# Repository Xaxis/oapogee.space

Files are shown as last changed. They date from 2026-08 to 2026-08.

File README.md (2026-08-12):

# oApogee

An open source telemetry payload for model rockets, and the documentation that
teaches you to build one. Site at **[oapogee.space](https://oapogee.space)**.

oApogee records altitude, acceleration and orientation through a flight, logs it
to onboard flash, and optionally downlinks it live over LoRa and reports GNSS
position for recovery. It attaches to a rocket you already own, in a printed pod
that needs no modification to the airframe.

**oApogee is a passive instrumentation payload. It does not fire ejection
charges, control deployment, ignite motors, or command any pyrotechnic device.**
That is a design boundary and it will not change. See
[content/safety.md](content/safety.md).

## Project status

**This is a design on paper.** Nothing has been fabricated, assembled, weighed,
priced, or flown. Every cost, mass, range and endurance figure on the site is
missing rather than estimated, and each gap records what evidence would close
it. The full list is at [oapogee.space/status](https://oapogee.space/status),
read from the content files when the site is built so it cannot go stale.

Design decisions that are still open are in
[docs/open-questions.md](docs/open-questions.md).

## The rule everything else follows from

**Never publish a number that has not been measured or sourced.**

The documentation is the product. The hardware is commodity: barometer, IMU,
microcontroller, radio, all of it available to anyone. What makes this project
worth existing is that a motivated beginner can follow the site start to finish
and end up with a working payload and a real flight graph. That only works if
every number on it is true.

So there are no estimates dressed as measurements. A figure that has not been
verified is written as a marker saying what evidence would close it, and the
build fails if the index of those markers goes stale. A site full of confident
fabricated specs is worse than useless in a hobby where people's build decisions
depend on them.

Two consequences you will notice immediately: the bill of materials has no
prices in it, and the homepage does not have a flight graph.

## Layout

```
content/     Prose pages, Markdown with YAML frontmatter
data/        Structured source: bom.yaml, tiers.yaml, glossary.yaml
docs/        Working documents, including the page map and the format specs
apps/web/    Next.js 15 App Router site, one renderer of content/ and data/
tools/       Checks: prose rules, data cross-references, marker index
```

`content/` and `data/` are the product. `apps/web/` renders them. Anything that
appears in more than one place on the site lives in `data/` as YAML, never as a
hand-written table inside a Markdown page, because two hand-written tables drift
and nothing catches it.

## Commands

Everything is a `make` target, and CI runs the same ones. `make` lists them.

```bash
make install     # dependencies, pinned to match CI
make dev         # the site, locally
make check       # everything CI runs
make check-fast  # the same without the site build
make hw          # re-render the schematic from hardware/oapogee.tsx
```

## Contributing

The most useful contribution to this project right now is telling us where it is
wrong. The safety and regulatory pages in particular are written carefully and
have not been reviewed by anyone with formal expertise in the rules they
describe.

Read [CONTRIBUTING.md](CONTRIBUTING.md) first, then
[CONTENT-STYLE.md](CONTENT-STYLE.md). Between them they cover the accuracy rule,
the voice, and the naming conventions, all of which are enforced in CI.

## Naming

The project is **oApogee**: lowercase `o`, capital `A`, one word. The `o` stands
for open.

**It is never shortened to "Apogee."** Apogee Components is the dominant
retailer in model rocketry and owns that word in this hobby completely. There is
no short form. oApogee is not affiliated with Apogee Components.

The three tiers are oApogee Solo, oApogee Link, and oApogee Track.

## Licence

Three, because this repository holds three different kinds of thing.

| What | Licence | SPDX |
|---|---|---|
| Hardware design files | CERN Open Hardware Licence v2, Strongly Reciprocal | `CERN-OHL-S-2.0` |
| Firmware and software | Apache License 2.0 | `Apache-2.0` |
| Documentation and content | Creative Commons Attribution-ShareAlike 4.0 | `CC-BY-SA-4.0` |

Full texts in [LICENSES/](LICENSES), and [LICENSE](LICENSE) says which applies
to which files and why. Reciprocal on the board because the plausible bad
outcome is a closed volume clone; permissive on the firmware because that is the
part worth having other people embed everywhere.

**The design is open. The name is not.** Build it, sell it, fork it, call it
something else. Licences do not stop somebody shipping a clone under this name;
a trademark does.

A project named for openness that ships a black box loses the audience it was
built for, so the intent is to publish the KiCad project rather than a PDF
schematic, the parametric CAD source rather than only STLs, and the full
firmware including calibration constants. Anything that cannot be opened will be
declared explicitly rather than quietly omitted.

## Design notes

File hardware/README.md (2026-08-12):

# oApogee hardware

The circuit, as source. `oapogee.tsx` is a [tscircuit](https://tscircuit.com)
design: the schematic is written as code, and the drawing, the netlist, the
machine-readable circuit JSON and a KiCad schematic are all rendered from it.

That is what makes the openness promise checkable rather than rhetorical. A
project whose first letter means open should publish the KiCad project, not a
PDF of a schematic, and this directory is where that comes from.

## What this is and is not

**This is a netlist. It is not a pinout.**

It says what connects to what, which is the design decision worth reviewing. It
does not say which physical pin of any package a signal lands on. The pin
numbers in the source are structural placeholders assigned in the order the
labels are written, not read from a datasheet.

That is deliberate. This project's rule is that it never publishes a number it
has not measured or sourced, and a datasheet pin number recalled from memory is
exactly the kind of confident, plausible, wrong figure the rule exists to
prevent. Mapping these functional pins onto real packages is a separate step,
done against datasheets, and it is tracked as an open item.

**Do not lay a board out from this and do not send anything here to a
fabricator.**

There is also deliberately no PCB or 3D output. A layout needs real footprints,
real footprints need the pin mapping that has not been done, and a routed board
built on placeholder pins would look far more finished than it is.

## Building it

```bash
make hw-deps   # once, installs tscircuit here
make hw        # render the artifacts into apps/web/public/hardware/
make check-hw  # verify the committed artifacts match the source
```

Outputs, in order of how much they can be trusted:

| Artifact | What it is |
|---|---|
| `oapogee-netlist.txt` | The connectivity, as text. Diffable, reviewable, and the thing to read first. |
| `oapogee-schematic.svg` | The same connectivity, drawn. |
| `oapogee.kicad_sch` | A KiCad schematic, for anyone who wants to take the design further. |
| `oapogee-circuit.json` | Machine readable, for anyone writing their own tooling. |

`make check-hw` compares the netlist and the schematic against a fresh render,
so the committed drawing cannot quietly stop matching the source. Circuit JSON
is excluded from that comparison because it embeds absolute paths from whichever
machine produced it.

## Two things that will bite you

**This directory keeps its own `node_modules` on purpose.** Installing tscircuit
at the repository root rehoists the workspace and moves `next` out of where
eslint expects to find it, which breaks lint and build for everyone who has
never opened a schematic. It is installed on demand by `make hw-deps` and is not
part of `yarn install`.

**The tscircuit CLI runs under [bun](https://bun.sh), not node.** Under node it
cannot load a `.tsx` entry point at all, and the error it gives says nothing
about bun. `tools/build-hardware.mjs` checks for bun and says so.

## Layout of the sheet

The schematic is arranged to read the same way the
[system block diagram](../data/system.yaml) does, because two drawings of the
same board that disagree about where things are is a tax on every reader:

- Power along the bottom left: USB-C, charger, cell, 3V3 rail.
- The microcontroller in the middle, with power and the host connection on its
  left side and every bus on its right.
- Flash to the left, since QSPI leaves that side.
- Sensors, radio, GNSS and the recovery aids in a column on the right.

Pin placement on the microcontroller is set explicitly with
`schPinArrangement`. Left to the default, pins land in declaration order and
every net crosses the part.

## Arming, and why it is a GPIO rather than a power switch

The flight state machine's first transition is operator-driven, so the board
carries an arming input. Arming is what starts the pressure reference settling
and the pre-arm ring buffer, and without an input there is no flight.

It is a GPIO, not a switch in the power path. oApogee is a passive payload, so
cutting power arms nothing and protects nobody. What the operator actually needs
is to power the payload up, let the GNSS get a fix and the barometer settle, and
then arm it once the rocket is on the rail, which a power switch cannot express.

The input is pulled up and the switch pulls it down, because a floating input
reads as noise and an input that reads as noise arms a rocket at random.

TODO(confirm): whether the switch is mechanical or magnetic. A slide or screw
switch is the rocketry convention and needs a hole in the pod. A reed or Hall
sensor arms through the wall with a magnet, which keeps the enclosure sealed
apart from its static ports, at the cost of a part that can be armed by anything
magnetic nearby. Decide before the enclosure is designed, because it changes the
pod.

## Battery sense

The telemetry format transmits a battery voltage in every FLIGHT and STATUS
packet, and beacon endurance after landing is the number that decides whether a
payload is findable the next morning. Neither is measurable without a divider: a
single cell reaches 4.2 V, which is above the 3V3 rail and above what the
microcontroller's ADC will accept.

## Open items

Listed at [oapogee.space/status](https://oapogee.space/status):

- Map every functional pin onto a real package pin, from datasheets.
- Choose the buck-boost regulator, currently a placeholder part.
- Set the charge current programming resistor, which follows from the cell
  capacity, which follows from an endurance requirement nobody has measured.
- Size the battery sense divider against the microcontroller's ADC input range
  and its input impedance, and decide whether it needs switching off between
  readings to stop it draining the cell on the pad.
- Decide the decoupling network properly rather than one capacitor per rail.
- Wire the IMU's data-ready interrupt. Polling a high rate sensor gives sample
  intervals that jitter with whatever else the loop is doing, and the log stores
  a timestamp per record precisely because that jitter is real.

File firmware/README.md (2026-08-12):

# oApogee firmware

The software that runs on the oApogee payload: the flight state machine, the
sensor fusion, the packet builders, the log writer, and the transmit scheduler.

**No build in this directory has ever run on hardware.** No board has been
fabricated, no image has been flashed, no packet has been transmitted, and no
flight has been logged. What exists here is the contract: headers, the field
tables the specs are encoded in, the build system, and two artifacts that
enforce the passive payload boundary mechanically. The implementations come
next, and they will still not have run on hardware when they arrive.

## What is here and what is not

Implemented:

| Part | State |
|---|---|
| Wire format tables, packets and log records | Written, checked against the specs at compile time |
| Public interfaces for every core module | Written |
| Flight state enumeration | Written by hand to the shape the generator will produce |
| Host build, warnings as errors | Builds on macOS clang and on Linux gcc |
| Output allowlist and undefined-symbol checks | Written and running |

Not implemented:

| Part | State |
|---|---|
| Every function body in `core/src/` | Stubs. The files contain an include and a comment |
| Everything in `port/` | Declarations only. There is no `port/src` |
| The application that ties them together | Does not exist |
| Tests | Do not exist. The build picks up `tests/` when it appears |
| The target build | Refuses to configure, with a message saying why |
| `tools/gen-states.mjs` | Does not exist. `gen/oa_states.h` is a hand-written copy of what it will emit |

## Why C

Three reasons, in order of weight.

The payload writes samples in an interrupt-adjacent context on a
microcontroller, into a fixed-width binary format, with no allocator and a
bounded stack. C is the language where that is the ordinary thing to do rather
than the thing you fight the runtime for.

The RP2350 ecosystem is C. The Pico SDK, the vendor sensor code a builder might
crib from, and every example a beginner will find are C, and a payload written
in something else makes every one of those a translation exercise for the person
least equipped to do it.

The documentation is the product. Someone who has never used this project should
be able to read `oa_packet_fields.def` and see the wire format, without knowing a
build system or a language feature. C is small enough that the field table is
the interesting part of the file.

The costs are real. There is no type system helping here, no bounds checking,
and no ownership model. What this codebase does instead is keep the dangerous
surface small: no allocation anywhere in core, no global mutable state, buffers
owned by callers, and a warning set that treats every implicit conversion as an
error, because a silent narrowing in a packing function produces a number that is
wrong and plausible.

## The core and port split

```
firmware/
  core/           No SDK. No libc beyond string.h, stdint.h, stdbool.h, stddef.h.
    include/      The interfaces. This is the contract.
    src/          Implementations. Stubs today.
    allowed-undefined.txt
  gen/            Generated from data/. Do not hand-edit.
  port/           The hardware surface. Declarations only.
    include/
    outputs.allowlist
  CMakeLists.txt
```

`core/` holds everything that decides anything: the state machine, the
complementary filter, the barometric conversion, the pad reference accumulator,
the ring buffer, the scheduler, the packet builders, the log packers and the
configuration validator. It has no idea what a sensor is. It takes numbers in
and returns numbers out.

`port/` is every function that touches a peripheral, declared in two headers and
implemented nowhere yet. `oa_port.h` is the whole hardware surface: time,
sensors, storage, radio, console, watchdog. `oa_out.h` is separate and short,
because it is the list of physical outputs the firmware may drive and it is
meant to be read on its own.

**Core is the only part that can be tested today, and that is the point.** It
compiles with nothing installed but CMake and a compiler, on a laptop, with no
board in the room. So the interesting behaviour, the transitions, the fusion, the
apogee detection lag, the byte layout of every packet, is testable now rather
than after a board arrives. A test can drive an entire flight through the state
machine from a table of samples, including the flights that only happen when a
sensor fails, which is a category of test nobody runs by flying rockets.

The seam that makes this work is `oa_sink_t`. Core writes bytes into a sink and
knows nothing else: not LittleFS, not a flash part, not a radio. Tests point a
sink at a buffer and compare against the spec tables; the firmware points the
same code at flash. There is no second implementation of the packing to keep in
step.

## The field tables are the important part

`core/include/oapogee/oa_packet_fields.def` and `oa_log_fields.def` are X-macro
tables: one line per field, with its type and byte offset. Everything that needs
to know the layout expands the same table. The packet type enumeration, the
length constants, the body structs, the builder declarations and the conformance
test that dumps the layout all come from one list.

A field that moves moves in one place. Everything that disagreed with it either
stops compiling or fails a test. The stated body and total lengths from the spec
are checked against the field offsets by `_Static_assert`, so a body length
edited without its total length fails the build rather than the flight.

The log table carries each field's scale and unit as string literals, and the
manifest writer copies them verbatim into `meta.json`. That is deliberate: the
log format is self-describing, so a manifest that disagreed with the packer would
produce files that decode wrongly and look fine. Emitting both from one table
makes that impossible rather than unlikely. Strings also mean there is no float
formatter on the payload turning an exact scale factor like `1e-7` into an
approximate one, in the one file that tells a reader how to interpret every other
byte.

## There are no tuning constants in this firmware

Every flight threshold, interval, rate and window is unmeasured. There is no
hardware, nothing has flown, and no sensor noise floor has been characterised.

So none of them is a literal in a source file. They all live in `oa_config_t`,
they all start unset, and each one carries a string saying what measurement would
settle it. `oa_config_is_flightworthy()` refuses to arm while a required one is
missing, and the payload can print exactly which ones and what would close them.

A payload that will not arm is a payload telling the truth about what it knows.
That is the correct behaviour at this stage, and it is how this firmware avoids
shipping a guess that would fly.

Constants from the specs are not tunables and are in code where they belong: the
CRC polynomial, the field offsets, the record widths, the 50000 Pa pressure
offset, the 2.5 V battery offset. The test is whether the number would change if
somebody measured something.

## Building

```bash
cmake -S firmware -B firmware/build
cmake --build firmware/build
cmake --build firmware/build --target oa-check
```

Nothing but CMake 3.16 and a C11 compiler. Warnings are errors:
`-Wall -Wextra -Werror -Wconversion -Wshadow -Wvla -Wdouble-promotion`.

Linking `liboa_core.a` currently prints a warning that the archive defines no
symbols. That is correct: the sources are stubs.

`oa-check` runs the two enforcement checks. See [SAFETY.md](./SAFETY.md) for what
each one catches and why it exists.

The target build is declared and refuses to configure:

```bash
cmake -S firmware -B firmware/build-target -DOA_BUILD_TARGET=ON
# fatal error, with a message explaining that it needs the Pico SDK
```

## Where the specifications live

The firmware conforms to these. It never redefines them. Where the firmware and
one of these documents disagree, the firmware is wrong.

- `docs/spec/telemetry-packet.md`, the downlink wire format
- `docs/spec/log-format.md`, the onboard log
- `data/flight-phases.yaml`, the flight state machine

## Safety

oApogee is a passive instrumentation payload. It does not fire ejection charges,
control deployment, ignite motors, or command any pyrotechnic device.
[SAFETY.md](./SAFETY.md) describes how that boundary is enforced in code rather
than asserted in a comment.

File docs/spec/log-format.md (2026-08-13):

---
title: Onboard log format specification
description: How oApogee stores a flight on the payload. Directory layout, the self-describing manifest, fixed-width record layouts, and how to read one.
tier: all
difficulty: advanced
time_estimate: null
updated: 2026-08-11
status: draft
spec_version: 1
---

# Onboard log format specification

This is what oApogee writes to its own flash during a flight, and what you get
when you plug it into a laptop. It is published so that anyone can read a log
with their own tools, and so that a log written today is still readable in ten
years by someone who has never seen this project.

This document is normative.

**Version 1. Status: draft.** No flight has been logged. The layout is settled
enough to implement against and no byte of it has been written by real hardware.

## The three decisions this format is built on

**Fixed-width binary records, not CSV.** A flight computer writes samples in an
interrupt-adjacent context on a microcontroller with no floating point to spare
and a flash chip with a finite write bandwidth. Formatting a float to text costs
far more than storing four bytes, and text costs two to three times the space
for the same information. Converting to CSV is trivial on a laptop and expensive
on the payload, so it happens on the laptop.

**Self-describing through a manifest, not through a hardcoded layout.** Each
flight directory carries a `meta.json` that states the record layout in full:
every field, its offset, its type, and its scaling. A third-party tool reads the
manifest and can decode the records without knowing this document, and a log
written by a future firmware with an extra field still parses. The spec version
in the manifest tells you which document to consult when something is ambiguous;
it is not required to read the data.

The cost is a few hundred bytes of JSON per flight, which is nothing against the
records, and the benefit is that this format does not rot.

**One file per sample rate, not one interleaved stream.** Sensor samples come at
a high rate. GNSS fixes come at a low one. Interleaving them means either
padding the GNSS fields into every sensor record, which wastes most of the flash,
or tagging each record with a type, which makes the file no longer a flat array
and defeats the whole point of fixed-width. So they are separate files, each a
plain array of identical records, each loadable in one line:

```python
import numpy as np
records = np.fromfile("flight.bin", dtype=dtype_from_manifest)
```

## Directory layout

Logs live on the onboard flash under LittleFS. One directory per flight.

```
/flights/
  0001/
    meta.json      manifest: schema, calibration, layout, summary
    flight.bin     fixed-width sensor records, high rate
    gnss.bin       fixed-width position fixes, low rate (Track only)
  0002/
    ...
```

Directory names are zero-padded decimal, monotonically increasing, and never
reused. A flight number is assigned when the payload transitions into `ARMED`
and is written before any record is, so a flight that ends in a crash and a
truncated file still has a directory and a manifest.

**LittleFS, specifically, for a reason.** A payload can lose power at any
instant: an impact can break a battery connection, and a hard landing can reset
the microcontroller. A filesystem that corrupts on power loss loses the whole
flight, including the part that was already safely written. LittleFS is designed
to be power-loss resilient and to wear-level, and both properties are load
bearing here rather than nice to have.

## meta.json

Written when the flight directory is created, then rewritten at `LANDED` with
the summary filled in. The `summary` object is always present, including in the
manifest written at creation. Every member is `null` and `landed` is `false`
until the payload reaches `LANDED`. A manifest whose `landed` is still `false`
is itself information: the flight ended before landing was detected.

```json
{
  "spec_version": 1,
  "flight": 1,
  "device": {
    "id": "oapogee-000000000000",
    "tier": "track",
    "path": "board",
    "hw_rev": null,
    "fw_version": "0.1.0",
    "fw_git": "0000000"
  },
  "session": {
    "armed_utc": null,
    "armed_uptime_ms": 128394,
    "simulated": false
  },
  "calibration": {
    "pad_pressure_pa": 101325,
    "pad_pressure_samples": 0,
    "pad_temperature_dc": 0,
    "accel_bias_mg": [0, 0, 0],
    "gyro_bias_cdps": [0, 0, 0]
  },
  "streams": {
    "flight": {
      "file": "flight.bin",
      "record_bytes": 36,
      "endian": "little",
      "nominal_hz": null,
      "fields": [
        { "name": "t_ms",         "offset": 0,  "type": "u32", "scale": 0.001, "unit": "s" },
        { "name": "pressure_pa",  "offset": 4,  "type": "i32", "scale": 1,     "unit": "Pa" },
        { "name": "temp_dc",      "offset": 8,  "type": "i16", "scale": 0.1,   "unit": "degC" },
        { "name": "accel_mg",     "offset": 10, "type": "i16", "count": 3, "scale": 0.001, "unit": "g" },
        { "name": "gyro_cdps",    "offset": 16, "type": "i16", "count": 3, "scale": 0.01,  "unit": "deg/s" },
        { "name": "hg_accel_dg",  "offset": 22, "type": "i16", "count": 3, "scale": 0.1,   "unit": "g" },
        { "name": "alt_cm",       "offset": 28, "type": "i32", "scale": 0.01,  "unit": "m" },
        { "name": "vel_dm_s",     "offset": 32, "type": "i16", "scale": 0.1,   "unit": "m/s" },
        { "name": "state",        "offset": 34, "type": "u8",  "scale": 1,     "unit": "enum" },
        { "name": "flags",        "offset": 35, "type": "u8",  "scale": 1,     "unit": "bits" }
      ]
    },
    "gnss": {
      "file": "gnss.bin",
      "record_bytes": 16,
      "endian": "little",
      "nominal_hz": null,
      "fields": [
        { "name": "t_ms",   "offset": 0,  "type": "u32", "scale": 0.001, "unit": "s" },
        { "name": "lat_e7", "offset": 4,  "type": "i32", "scale": 1e-7,  "unit": "deg" },
        { "name": "lon_e7", "offset": 8,  "type": "i32", "scale": 1e-7,  "unit": "deg" },
        { "name": "alt_m",  "offset": 12, "type": "i16", "scale": 1,     "unit": "m" },
        { "name": "sats",   "offset": 14, "type": "u8",  "scale": 1,     "unit": "count" },
        { "name": "fix",    "offset": 15, "type": "u8",  "scale": 1,     "unit": "enum" }
      ]
    }
  },
  "summary": {
    "apogee_m": null,
    "t_apogee_ms": null,
    "max_accel_g": null,
    "max_velocity_m_s": null,
    "flight_duration_ms": null,
    "landed": false
  }
}
```

**Every value in the example above is illustrative**, including the ones that
look like measurements. `armed_uptime_ms` is there to show the field's type and
magnitude, not to report anything: no payload has run, so no uptime has been
recorded. The example is a shape, not data.

Two values in it are not free to vary, and a writer must emit them as shown: the
`summary` members really are `null` and `landed` really is `false` in the
manifest written at flight-directory creation.

### Fields that are not obvious

`device.id` is derived from the microcontroller's unique identifier. It is stable
across reflashes, which is what makes a flight archive able to group flights by
airframe.

`session.armed_utc` is null on Solo and Link, and set on Track once a GNSS fix
provides UTC. There is no real-time clock on this board, which is a deliberate
omission: a coin cell and a crystal cost mass and money to provide a timestamp
that a laptop supplies for free at offload. Every time in the log is relative to
arming, and absolute time is attached afterwards where it is available.

`session.simulated` is the same idea as the `SIM` flag in the packet spec, and
it is here for the same reason. A bench run produces a complete, plausible log.
Without this field a flight archive will eventually publish one as a flight.

`calibration.pad_pressure_pa` is the zero reference the entire altitude column is
measured against, and publishing it is what makes the log re-derivable. If the
reference was taken badly, an analyst can recompute altitude from
`pressure_pa` rather than discarding the flight.

`calibration.pad_pressure_samples` is how many samples went into that average.
A reference taken from a short settling window is less trustworthy than one taken
over a long pad wait, and the reader deserves to know which they have.

`streams.*.nominal_hz` is the configured rate, not the achieved one. Actual
sample intervals are in the records, and they are what should be used. A log rate
that varies by flight phase makes the nominal figure a hint, not a fact.

`streams` lists exactly the files present in the flight directory, and nothing
else. A build with no GNSS receiver writes no `gnss.bin` and carries no `gnss`
key. The manifest above is a Track log; a Solo or Link log has `flight` only.
This is the one place structure varies by build variant. Within a stream the
record layout never does, which is why `hg_accel_dg` keeps its six bytes on a
build with no high-g part. A reader discovers streams by enumerating `streams`,
never by assuming a name.

## flight.bin record, 36 bytes

| Offset | Size | Type | Field | Unit | Notes |
|---|---|---|---|---|---|
| 0 | 4 | u32 | `t_ms` | ms | Since arming |
| 4 | 4 | i32 | `pressure_pa` | Pa | Raw barometer reading |
| 8 | 2 | i16 | `temp_dc` | 0.1 degC | Barometer die temperature |
| 10 | 6 | i16 x3 | `accel_mg` | mg | IMU accelerometer, X Y Z |
| 16 | 6 | i16 x3 | `gyro_cdps` | 0.01 deg/s | IMU gyroscope, X Y Z |
| 22 | 6 | i16 x3 | `hg_accel_dg` | 0.1 g | High-g accelerometer, X Y Z |
| 28 | 4 | i32 | `alt_cm` | cm | Fused altitude above pad |
| 32 | 2 | i16 | `vel_dm_s` | 0.1 m/s | Fused vertical velocity |
| 34 | 1 | u8 | `state` | enum | Flight state |
| 35 | 1 | u8 | `flags` | bits | Same bit assignments as the packet spec |

**Raw and derived are both stored, deliberately.** `pressure_pa` and the raw IMU
axes are what the sensors said. `alt_cm` and `vel_dm_s` are what the fusion
concluded. Storing only the derived values would make the log unauditable: a
bug in the filter would be invisible, and nobody could reprocess an old flight
with a better filter. Storing only raw would mean the log disagrees with what
the payload transmitted and what it used to detect apogee. Twelve of the
thirty-six bytes buy the ability to check the payload's own work, and that is
the best-value spend in this format.

`hg_accel_dg` is all zeros when no high-g part is fitted, and the `HIGH_G` flag
is clear. It occupies its six bytes regardless, because a record layout that
changes width by build variant is not a fixed-width record.

`gyro_cdps` in hundredths of a degree per second covers plus or minus 327.67
deg/s, which is under one revolution per second. It is the only field in this
record whose container is narrower than the quantity it carries: `accel_mg`
covers plus or minus 32.767 g, and `hg_accel_dg` covers plus or minus 3276.7 g.
A rocket rolling faster than 327.67 deg/s clips this channel, and a clipped gyro
axis reads as a flat plateau for exactly the reason a saturated accelerometer
does.

TODO(verify): state the gyro full-scale range oApogee configures, which is the
same open question recorded against the `imu` part in `data/bom.yaml`, and
compare it against the 327.67 deg/s this encoding can hold.

TODO(confirm-on-hardware): record the peak roll rate on a flight. If either that
figure or the configured range exceeds 327.67 deg/s, widen this field before
anything depends on `spec_version` 1, because `flight.bin` is a fixed-width
record and changing it afterwards is a format break.

The state enumeration is the one in `data/flight-phases.yaml` and the packet
spec: 0 `PAD_IDLE` through 6 `LANDED`.

At 36 bytes per record, a stream running at 100 Hz produces 3.6 kB per second.
A one-minute flight logged entirely at that rate is roughly 216 kB.

TODO(verify): the actual per-phase log rates have not been chosen. Once they
are, publish the resulting file size for a representative flight and use it to
size the flash part, rather than defaulting to 16 MB because it is the reflexive
choice.

## gnss.bin record, 16 bytes

| Offset | Size | Type | Field | Unit |
|---|---|---|---|---|
| 0 | 4 | u32 | `t_ms` | ms since arming |
| 4 | 4 | i32 | `lat_e7` | degrees x 10^7 |
| 8 | 4 | i32 | `lon_e7` | degrees x 10^7 |
| 12 | 2 | i16 | `alt_m` | 1 m, GNSS altitude |
| 14 | 1 | u8 | `sats` | satellites used |
| 15 | 1 | u8 | `fix` | fix type |

`alt_m` is the receiver's own altitude solution and is **not** the same
measurement as `alt_cm` in `flight.bin`. GNSS altitude is referenced to an
ellipsoid, not to the launch pad, and it is considerably less precise than the
barometer for this application. It is stored because disagreement between the
two is diagnostically useful, not because it is a better altitude. Anyone
plotting a flight should use the barometric column.

Whole metres are deliberate. This is an absolute altitude, so unlike `alt_cm`
the field has to hold the site elevation as well as everything the airframe
adds. An i16 of metres covers minus 32768 to 32767 m, which is far outside the
envelope of any airframe this payload is built for. Tenths of a metre in the
same two bytes would cover only plus or minus 3276.7 m, which a mountain site
plus a large flight can reach, and the extra digit would be false precision in
any case, since GNSS vertical accuracy is much coarser than a decimetre. A
solution outside the representable range is clamped to the endpoint rather than
allowed to wrap, because a wrapped value decodes as a plausible altitude with
the wrong sign and nothing marks it as wrong.

Fix types follow the u-blox convention: 0 no fix, 2 two-dimensional, 3
three-dimensional. Other values are passed through unchanged.

A record is only appended when the receiver reports a fix. Gaps in `t_ms` are
real and mean the receiver had no solution, which happens under boost and is
worth being able to see.

## Truncation and partial files

A file may end mid-record. This is normal: it is what a payload that lost power
on impact leaves behind, and that flight's data is still worth having.

A reader **must** treat a trailing partial record as absent, use
`floor(file_size / record_bytes)` records, and not error out. A reader **should**
report that truncation occurred, because a log that ends abruptly at apogee is
telling you something about the flight.

## Export

The payload does not convert anything. Export is a host-side operation over USB,
producing:

- **CSV**, one row per record, columns named from the manifest with units in the
  header, scaling applied. This is what opens in a spreadsheet.
- **JSON**, the manifest plus decoded records, for programmatic use.

Both are lossless with respect to the binary, because scaling factors are exact
powers of ten and the integers are exactly representable.

The binary is the archival copy. CSV and JSON are conveniences derived from it,
and the Flight Log submission format takes the binary plus its manifest, not the
CSV, for exactly that reason.

## Reference reader

Reads any version of this format, because it reads the manifest rather than
this document:

```python
import json
import numpy as np

TYPES = {"u8": "u1", "i8": "i1", "u16": "u2", "i16": "i2", "u32": "u4", "i32": "i4"}

def load(flight_dir, stream="flight"):
    with open(f"{flight_dir}/meta.json") as f:
        meta = json.load(f)

    # A stream is absent when the build did not write it, so name what is here
    # rather than failing on a bare key lookup a caller cannot interpret.
    spec = meta["streams"].get(stream)
    if spec is None:
        raise KeyError(
            f"no {stream!r} stream in this log; present: {sorted(meta['streams'])}"
        )

    order = "<" if spec["endian"] == "little" else ">"

    names, formats, offsets = [], [], []
    for field in spec["fields"]:
        count = field.get("count", 1)
        base = order + TYPES[field["type"]]
        names.append(field["name"])
        formats.append((base, count) if count > 1 else base)
        offsets.append(field["offset"])

    dtype = np.dtype(
        {"names": names, "formats": formats, "offsets": offsets, "itemsize": spec["record_bytes"]}
    )

    # A trailing partial record is normal: it is what a payload that lost power
    # on impact leaves behind. Truncate to whole records rather than failing.
    raw = np.fromfile(f"{flight_dir}/{spec['file']}", dtype=np.uint8)
    n = len(raw) // spec["record_bytes"]
    truncated = len(raw) % spec["record_bytes"] != 0
    records = raw[: n * spec["record_bytes"]].view(dtype)

    scaled = {
        f["name"]: records[f["name"]] * f["scale"] if f["scale"] != 1 else records[f["name"]]
        for f in spec["fields"]
    }
    return meta, scaled, truncated
```

## Conformance

A conforming reader:

- **must** read the layout from `meta.json` rather than assuming this document
- **must** discover streams by enumerating `streams` rather than assuming a
  stream name is present
- **must** truncate a trailing partial record rather than failing
- **must** treat a null summary member, or `landed` false, as not known rather
  than as a measured zero
- **must not** treat `session.simulated` as decorative
- **should** report truncation
- **should** prefer `alt_cm` over `alt_m` when plotting altitude, and should say
  which it used

A conforming writer:

- **must** write `meta.json` before the first record
- **must** write the `summary` object in the manifest it writes before the first
  record, with every member `null` and `landed` `false`
- **must not** list a stream in `streams` that it did not write a file for
- **must** write the calibration reference actually used
- **must** set `simulated` on any run not produced by a real flight
- **should** rewrite `meta.json` with the summary at `LANDED`

## Open questions

Decided: block checksums go in the manifest, which every flight already writes,
rather than interleaved into `flight.bin` or into a third file. Interleaving
would break the flat-array property that makes this format one line to load,
which is most of why it is shaped this way, and a sidecar would add a file when
a suitable one already exists. A reader that does not care about integrity
ignores the manifest exactly as it does today.

TODO(confirm-on-hardware): implement it in the log writer and state the block
size, which should match the flash page size of the part actually fitted rather
than be picked now.

TODO(verify): confirm that LittleFS on the chosen flash part actually survives
power loss mid-write in practice, by testing it: write continuously and cut
power repeatedly, then check that every completed record is intact. This is the
assumption the whole storage design rests on and it should be demonstrated
rather than trusted.

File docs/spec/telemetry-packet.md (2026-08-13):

---
title: Telemetry packet specification
description: The oApogee downlink wire format. Byte layout, packet types, field encodings, and the rules a conforming receiver must follow.
tier: link
difficulty: advanced
time_estimate: null
updated: 2026-08-11
status: draft
spec_version: 1
---

# Telemetry packet specification

This is the format oApogee Link and oApogee Track transmit over the air. It is
published so that anyone can write a receiver, a decoder, or a logger without
reverse engineering anything.

This document is normative. Where the firmware and this document disagree, one
of them is a bug, and which one is decided by whichever is easier to change
without breaking existing receivers.

**Version 1. Status: draft.** Nothing has been transmitted by real hardware yet.
The layout is settled enough to implement against, and the field ranges have
been chosen deliberately, but no byte of this has been observed on a radio.

## Design constraints, and what they cost

Four constraints shaped every decision below.

**Airtime is the scarce resource.** LoRa trades data rate for range, and a
telemetry packet competes for the air with every retry of the packet before it.
A packet twice as long takes roughly twice as long to send, halving the update
rate at the same settings. So the format is byte-packed with no alignment
padding, no field names, and no self-description on the wire.

**The receiver may miss any packet, and must not care.** Every packet is
independent. There is no state carried between packets, no delta encoding, and
no requirement to have seen packet N to decode packet N+1. A ground station that
comes up halfway through a flight decodes the next packet it hears.

**No encryption, ever.** Amateur radio rules prohibit messages encoded to
obscure their meaning, and oApogee intends to remain legal for licensed
operators to transmit under Part 97. Binary and compact is efficiency; scrambled
is obfuscation. This format is the former and will not become the latter.

**Nothing here can command the vehicle.** The link is downlink-only in the sense
that matters: there is no packet type that causes the payload to do anything. A
receiver cannot arm it, cannot trigger anything, and cannot deploy anything,
because oApogee has no mechanism to deploy. See
[Safety and rules](../../content/safety.md).

The cost of all this: the format is not human-readable, it is not extensible in
place, and adding a field means a version bump. Those are accepted.

## Conventions

- All multi-byte integers are **little-endian**. Both ends of this link run on
  ARM Cortex-M cores that are natively little-endian, so this costs nothing on
  either side. A receiver on a big-endian host must byte-swap.
- Integers are two's complement where signed.
- There is no padding and no alignment. A struct overlay works on Cortex-M and
  x86 with packed attributes; a portable decoder should read field by field.
- Offsets are in bytes from the start of the packet.
- `u16`, `i32` and so on are unsigned and signed integers of that bit width.

## Packet structure

```
+----------------+------------------------+---------+
| header, 8 B    | body, type-dependent   | CRC 2 B |
+----------------+------------------------+---------+
```

Total length is fixed per packet type, so a receiver knows how many bytes to
expect from the type field alone. There is no length field, because a length
field costs a byte on every packet to describe something already known.

### Header, 8 bytes

| Offset | Size | Type | Field | Notes |
|---|---|---|---|---|
| 0 | 1 | u8 | `hdr` | High nibble: format version. Low nibble: packet type. |
| 1 | 1 | u8 | `flags` | Bit field, see below. |
| 2 | 1 | u8 | `seq` | Increments per transmitted packet, wraps at 255. |
| 3 | 1 | u8 | `state` | Flight state, see below. |
| 4 | 4 | u32 | `t_ms` | Milliseconds since the transition into `ARMED`. Transmitted as 0 while `state` is `PAD_IDLE`. |

`hdr` packs version and type into one byte because both are small and a whole
byte for each is a byte per packet spent on nothing. Version 1 with a `FLIGHT`
packet is `0x12`.

A receiver **must** reject a packet whose version nibble it does not recognise,
rather than attempting to decode it. Field offsets are not guaranteed stable
across versions.

`seq` exists so a receiver can count losses and report link quality honestly. It
wraps every 256 packets, which is unambiguous at any realistic packet rate.

`t_ms` is zero at the moment of arming, not at power-on and not at launch. It is
a `u32` of milliseconds, giving a range of about 49 days, which is not a
constraint anyone will meet. The zero point is arming rather than launch because
launch detection happens after the fact, and a timebase that only becomes valid
retroactively is a poor timebase.

Before arming there is no elapsed time to report, so `t_ms` is transmitted as 0
in every packet whose `state` is `PAD_IDLE`. It is not the power-on uptime: the
payload's uptime counter is a firmware implementation detail and is never on the
air. A pad packet is therefore identified by `state`, not by a clock, and a run
of `STATUS` packets on the pad all carry `t_ms` of 0.

### Flags

This table is the normative home for the bit assignments. The mask column is
here so that nothing elsewhere has to restate them to be useful.

| Bit | Mask | Name | Meaning when set |
|---|---|---|---|
| 0 | `0x01` | `GNSS_FIX` | The GNSS receiver has a position fix. |
| 1 | `0x02` | `HIGH_G` | The high-g accelerometer is present and healthy. |
| 2 | `0x04` | `BARO_FAULT` | The barometer has failed or is returning implausible values. |
| 3 | `0x08` | `IMU_FAULT` | The IMU has failed or is returning implausible values. |
| 4 | `0x10` | `LOG_FULL` | Onboard storage is full. Logging has stopped. |
| 5 | `0x20` | `LOW_BATT` | Battery below the low threshold. |
| 6 | `0x40` | `SIM` | This packet was produced by a simulation or bench test, not a flight. |
| 7 | `0x80` | reserved | Must be transmitted as 0 and ignored on receive. |

`SIM` is not optional decoration. A bench test transmits real-looking packets,
and a flight log archive that cannot distinguish a bench run from a flight will
eventually publish a bench run as a flight. It is one bit and it prevents a
whole category of quiet data corruption.

Fault flags report an instrument that stopped working. They never cause a field
to be omitted, because omission would change the packet length. A faulted
sensor's fields carry the last value read, and the flag is what tells you not to
trust them. The alternative, transmitting a sentinel, produces a plot with a
spike in it rather than a gap, which is worse.

That rule governs a sensor that is reading badly. Position is the other case:
with no fix there is no last value worth carrying, so `lat_e7` and `lon_e7`
carry `INT32_MIN` in both `BEACON` and `POSITION`, and `GNSS_FIX` says which it
is. A sentinel is right when the quantity is absent and wrong when it is merely
suspect.

### Flight state

Values match `order` in `data/flight-phases.yaml`, which is the same enumeration
the firmware and the log format use.

| Value | State |
|---|---|
| 0 | `PAD_IDLE` |
| 1 | `ARMED` |
| 2 | `BOOST` |
| 3 | `COAST` |
| 4 | `APOGEE` |
| 5 | `DESCENT` |
| 6 | `LANDED` |

Values 7 to 255 are reserved. A receiver encountering one should display the
number rather than guessing, and must not treat it as an error.

## Packet types

| Type | Name | Body | Total | Sent |
|---|---|---|---|---|
| 0x1 | `STATUS` | 3 B | 13 B | On the pad, low rate |
| 0x2 | `FLIGHT` | 9 B | 19 B | Boost through descent, high rate |
| 0x3 | `APOGEE` | 8 B | 18 B | Immediately on apogee detection, repeated |
| 0x4 | `BEACON` | 12 B | 22 B | After landing, low rate |
| 0x5 | `POSITION` | 9 B | 19 B | Track only, interleaved |

Types 0x0 and 0x6 to 0xF are reserved.

### 0x1 STATUS

Sent while the payload is on the pad, so that a ground station shows something
before the flight and so the operator can confirm the link works before walking
away from the rail. Low rate by design.

| Offset | Size | Type | Field | Encoding |
|---|---|---|---|---|
| 8 | 2 | u16 | `pad_pressure_pa_off` | Ground reference pressure, offset pascals. |
| 10 | 1 | u8 | `batt` | Battery, see encoding below. |

`pad_pressure_pa_off` is the establishing pressure reference in whole pascals,
offset so the useful range fills 16 bits exactly: the transmitted value is
`pressure_pa - 50000`, and the 65536 representable values cover 50000 to 115535
Pa. The low end is roughly 5500 m of pressure altitude and the high end is above
any recorded surface pressure, so the band covers any plausible launch site. A
reading below 50000 Pa is transmitted as 0, a reading above 115535 Pa is
transmitted as 65535, and `BARO_FAULT` is set in either case.

The offset is what earns the resolution. Without it a u16 of whole pascals would
stop at 65535 Pa, which is lower than the pressure at any launch site anyone
flies from, so the reference would not be representable at all. With it, the
same two bytes carry 1 Pa steps across the whole band. Whole pascals also match
`calibration.pad_pressure_pa` in the [log format](./log-format.md), so the same
quantity is not on two scales in two specifications. This field is the zero the
entire altitude column is measured against, which is why it is not coarsened to
save arithmetic.

### 0x2 FLIGHT

The main telemetry packet. Sent at the highest rate the radio settings allow
from boost through descent.

| Offset | Size | Type | Field | Encoding |
|---|---|---|---|---|
| 8 | 4 | i32 | `alt_cm` | Fused altitude above the pad, centimetres. |
| 12 | 2 | i16 | `vel_dm_s` | Fused vertical velocity, decimetres per second. |
| 14 | 2 | i16 | `accel_cg` | Vertical acceleration, hundredths of g. |
| 16 | 1 | u8 | `batt` | Battery, see encoding below. |

`alt_cm` is signed, and negative values are legitimate rather than a bug. A
barometric zero taken on the pad reports negative altitude if the rocket lands
below the pad or if pressure rises during the flight. A receiver that clamps
this at zero is hiding a real measurement, and there is a troubleshooting entry
for exactly this confusion.

`vel_dm_s` in decimetres per second covers plus or minus 3276.7 m/s, which is
far more than needed and costs nothing over a tighter scale. Positive is up.

`accel_cg` in hundredths of g covers plus or minus 327.67 g. This is
deliberately wider than a 6-axis IMU can measure, because the field carries the
high-g accelerometer's reading when that part is fitted. When `HIGH_G` is clear,
the value came from the IMU and is subject to saturation: a boost that reads a
flat value at the IMU's full-scale limit is saturation, not a constant
acceleration.

### 0x3 APOGEE

Sent the instant apogee is detected, then repeated a small number of times.

Apogee is the number the entire payload exists to produce, and it is the number
most likely to be lost: it happens once, at the greatest distance from the
receiver, and it is followed by the deployment event that is the most likely
moment for the payload to be damaged. So it gets its own packet type, sent
immediately rather than waiting for the next scheduled transmission, and
repeated so a single dropped packet does not lose it.

| Offset | Size | Type | Field | Encoding |
|---|---|---|---|---|
| 8 | 4 | i32 | `apogee_cm` | Peak altitude above the pad, centimetres. |
| 12 | 4 | u32 | `t_apogee_ms` | Time of apogee, milliseconds since arming. |

`t_apogee_ms` is the estimated time of the apogee event, which is earlier than
the `t_ms` in the header of the packet reporting it. The difference is the
detection lag, and a receiver may display it. Apogee detection requires
confirmation across multiple descending samples, so the lag is real and
non-zero.

TODO(verify): state the detection lag in milliseconds once the confirmation
sample count is chosen from measured barometer noise. A reader is entitled to
know the size of the error in the recorded apogee time.

### 0x4 BEACON

Sent after landing, at a long interval, to conserve battery while remaining
findable.

| Offset | Size | Type | Field | Encoding |
|---|---|---|---|---|
| 8 | 4 | i32 | `lat_e7` | Latitude, degrees times 10^7. `INT32_MIN` if no fix. |
| 12 | 4 | i32 | `lon_e7` | Longitude, degrees times 10^7. `INT32_MIN` if no fix. |
| 16 | 4 | i32 | `apogee_cm` | Peak altitude of the flight just completed. |

Degrees times 10^7 is the u-blox native scaling, so no conversion happens on the
payload, and its resolution is far finer than the position accuracy, which means
the encoding never limits the fix.

A Solo or Link build with no GNSS transmits `INT32_MIN` in both position fields
and leaves `GNSS_FIX` clear. `INT32_MIN` is used rather than zero because zero
is a real coordinate.

The beacon repeats the flight's apogee so that a walkaway recovery still yields
the number even if the onboard log is unreadable afterwards.

### 0x5 POSITION

Track only. Interleaved with `FLIGHT` packets during flight at a lower rate,
because position changes slowly compared to altitude and is not worth the
airtime at the flight packet rate.

| Offset | Size | Type | Field | Encoding |
|---|---|---|---|---|
| 8 | 4 | i32 | `lat_e7` | Latitude, degrees times 10^7. `INT32_MIN` if no fix. |
| 12 | 4 | i32 | `lon_e7` | Longitude, degrees times 10^7. `INT32_MIN` if no fix. |
| 16 | 1 | u8 | `sats` | Satellites used in the fix. Zero when `GNSS_FIX` is clear. |

`POSITION` is transmitted on its scheduled slot whether or not the receiver has
a fix. Suppressing it would make a fix outage indistinguishable from a lost
packet, and `seq` gaps are supposed to mean lost packets and nothing else. When
`GNSS_FIX` is clear, both position fields carry `INT32_MIN` and `sats` carries
zero, for the same reason `BEACON` uses that sentinel: zero is a real
coordinate.

`GNSS_FIX` in the header is authoritative. A receiver **must** check it before
plotting, and **must not** plot a position from a packet whose `GNSS_FIX` is
clear, even if the coordinate fields look plausible. A fix lost under boost is
normal, and the log format records the same outage as a gap rather than as a
coordinate.

## CRC

The last two bytes of every packet are a CRC-16/CCITT-FALSE over all preceding
bytes of the packet, transmitted little-endian.

Parameters: polynomial `0x1021`, initial value `0xFFFF`, no input reflection, no
output reflection, no final XOR.

**Why a CRC when LoRa already has one.** The radio's CRC covers the air
interface and nothing else. It does not cover the serial link between the
receiver module and the host, it does not cover a receiver library that hands
back a truncated buffer, and it does not cover a payload firmware bug that
assembles a malformed packet and transmits it correctly. Two bytes on a
nineteen-byte packet is a tenth of the payload, and it is worth it: a corrupted
altitude that decodes cleanly is indistinguishable from a real one, and this
project's entire claim is that its numbers are true.

TODO(verify): state what those two bytes actually cost in airtime, at the
spreading factor and bandwidth oApogee ends up using. It is not a tenth. LoRa
airtime is quantised into symbols and carries a preamble and header that a
short packet does not amortise, so the fraction has to be computed from the
modem's own timing formula and stated with the settings it assumes.

A receiver **must** discard any packet whose CRC does not match, and **should**
count discards so link quality can be reported.

## Transmission scheduling

Rates are not specified here as absolute numbers, because the achievable rate
depends on the spreading factor, bandwidth and coding rate, and those are
configuration rather than protocol.

The scheduling rules that are normative:

1. `APOGEE` preempts everything. It is queued the moment apogee is detected and
   transmitted at the next opportunity, ahead of any pending packet.
2. `FLIGHT` runs at the fastest sustainable rate from `BOOST` through `DESCENT`.
3. `POSITION` is interleaved at a fraction of the `FLIGHT` rate on Track builds.
4. `STATUS` runs slowly during `PAD_IDLE` and `ARMED`.
5. `BEACON` runs slowly after `LANDED`, and the interval lengthens over time to
   trade update rate for endurance during a long search.

TODO(verify): publish the actual intervals for each state at the shipped radio
configuration, measured, along with the resulting duty cycle, so that anyone
checking regional duty cycle limits can do the arithmetic. This matters for EU
and UK builds in particular.

## Conformance

A conforming receiver:

- **must** reject packets with an unrecognised version nibble
- **must** verify the CRC and discard packets that fail
- **must** treat unknown packet types as unreadable rather than misparsing them
- **must** treat unknown state values as unknown rather than as an error
- **must not** clamp `alt_cm` at zero
- **must not** treat `t_ms` as elapsed time while `state` is `PAD_IDLE`, where it
  is always 0, and must not compute an interval spanning the transition out of
  `PAD_IDLE`
- **must not** plot a position from a packet whose `GNSS_FIX` is clear, in which
  case both coordinate fields carry `INT32_MIN`
- **should** count sequence gaps and CRC failures and expose both
- **must** display the `SIM` flag prominently, and must never publish a `SIM`
  packet to a flight archive as a real flight
- **should** surface fault flags next to the affected values rather than hiding
  them

## Reference decoder

Field by field, no struct overlay, portable to any host:

```python
import struct

MAGIC_VERSION = 1
TYPE_NAMES = {1: "STATUS", 2: "FLIGHT", 3: "APOGEE", 4: "BEACON", 5: "POSITION"}
BODY_LEN = {1: 3, 2: 9, 3: 8, 4: 12, 5: 9}
INT32_MIN = -(2 ** 31)

def crc16_ccitt_false(data: bytes) -> int:
    crc = 0xFFFF
    for byte in data:
        crc ^= byte << 8
        for _ in range(8):
            crc = ((crc << 1) ^ 0x1021) & 0xFFFF if crc & 0x8000 else (crc << 1) & 0xFFFF
    return crc

def decode(packet: bytes) -> dict:
    if len(packet) < 10:
        raise ValueError("short packet")

    version = packet[0] >> 4
    ptype = packet[0] & 0x0F
    if version != MAGIC_VERSION:
        raise ValueError(f"unsupported version {version}")
    if ptype not in BODY_LEN:
        raise ValueError(f"unknown packet type {ptype}")

    expected = 8 + BODY_LEN[ptype] + 2
    if len(packet) != expected:
        raise ValueError(f"expected {expected} bytes, got {len(packet)}")

    (received_crc,) = struct.unpack_from("<H", packet, len(packet) - 2)
    if crc16_ccitt_false(packet[:-2]) != received_crc:
        raise ValueError("CRC mismatch")

    flags = packet[1]
    out = {
        "type": TYPE_NAMES[ptype],
        "flags": flags,
        "gnss_fix": bool(flags & 0x01),
        "high_g": bool(flags & 0x02),
        "baro_fault": bool(flags & 0x04),
        "imu_fault": bool(flags & 0x08),
        "log_full": bool(flags & 0x10),
        "low_batt": bool(flags & 0x20),
        "simulated": bool(flags & 0x40),
        "seq": packet[2],
        "state": packet[3],
        "t_ms": struct.unpack_from("<I", packet, 4)[0],
    }

    if ptype == 1:  # STATUS
        pad_off, batt = struct.unpack_from("<HB", packet, 8)
        out.update(
            pad_pressure_pa=50000 + pad_off,
            battery_v=2.5 + batt / 100.0,
        )
    elif ptype == 2:  # FLIGHT
        alt_cm, vel_dm_s, accel_cg, batt = struct.unpack_from("<ihhB", packet, 8)
        out.update(
            altitude_m=alt_cm / 100.0,
            velocity_m_s=vel_dm_s / 10.0,
            accel_g=accel_cg / 100.0,
            battery_v=2.5 + batt / 100.0,
        )
    elif ptype == 3:  # APOGEE
        apogee_cm, t_apogee_ms = struct.unpack_from("<iI", packet, 8)
        out.update(apogee_m=apogee_cm / 100.0, t_apogee_ms=t_apogee_ms)
    elif ptype == 4:  # BEACON
        lat_e7, lon_e7, apogee_cm = struct.unpack_from("<iii", packet, 8)
        # GNSS_FIX is authoritative, per Conformance. Deciding from the sentinel
        # alone would plot a coordinate sent with the flag clear, which is the
        # one thing a receiver must not do.
        no_fix = not out["gnss_fix"] or lat_e7 == INT32_MIN or lon_e7 == INT32_MIN
        out.update(
            lat=None if no_fix else lat_e7 / 1e7,
            lon=None if no_fix else lon_e7 / 1e7,
            apogee_m=apogee_cm / 100.0,
        )
    elif ptype == 5:  # POSITION
        lat_e7, lon_e7, sats = struct.unpack_from("<iiB", packet, 8)
        no_fix = not out["gnss_fix"] or lat_e7 == INT32_MIN or lon_e7 == INT32_MIN
        out.update(
            lat=None if no_fix else lat_e7 / 1e7,
            lon=None if no_fix else lon_e7 / 1e7,
            satellites=sats,
        )
    else:
        # Unreachable today. It exists so that adding a type to BODY_LEN without
        # a body branch fails loudly instead of returning a header-only decode
        # that looks like a packet with no body.
        raise ValueError(f"no body decoder for type {ptype}")

    return out
```

## Battery encoding

One byte, `battery_volts = 2.5 + batt / 100`. Range 2.50 V to 5.05 V in 10 mV
steps.

The floor is 2.5 V because a single cell below that is already past the point
its protection circuit should have disconnected, so finer resolution down there
would describe a state that should not occur. The ceiling covers USB present.

## Changing this format

Adding a field to an existing packet type changes its length and breaks every
existing receiver, so it is a version bump, not an addition.

The cheap ways to extend without a bump, in order of preference:

1. Use a reserved flag bit.
2. Use a reserved packet type. Old receivers reject unknown types cleanly, which
   is exactly the designed behaviour, so a new type is additive.
3. Bump the version nibble and publish version 2 alongside version 1.

The version nibble has 16 values. If this format reaches version 16 something
has gone wrong upstream of the format.

## Open questions

Decided: a flag, with the conformance rule strengthened to compensate. A
distinct type is not one type but a parallel type for every packet type that can
be simulated, which doubles the type space to encode a property orthogonal to
what the packet contains, and ten of the sixteen type values are already
reserved for extension. The risk that a receiver ignores the flag is addressed
directly instead: displaying `SIM` prominently is a **must**, not a *should*.

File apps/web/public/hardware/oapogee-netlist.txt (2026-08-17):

COMPONENTS:
 - J1: USB4085-GF-A
 - R1: 5.1kΩ res0402 resistor
 - R2: 5.1kΩ res0402 resistor
 - U1: MCP73831, sot23_5
 - R3: 10kΩ res0402 resistor
 - J2: S2B-PH-K-S, jst_ph_2
 - U2: TPS63001
 - L2: L2, source_component
 - C1: 10uF cap0805 capacitor
 - C2: 22uF cap0805 capacitor
 - U3: RP2350A
 - C3: 100nF cap0402 capacitor
 - Y1: ABM8-272-T3
 - C4: 15pF cap0402 capacitor
 - C11: 100nF cap0402 capacitor
 - C12: 1uF cap0603 capacitor
 - C8: 100nF cap0402 capacitor
 - C9: 2.2uF cap0603 capacitor
 - C10: 10nF cap0402 capacitor
 - C6: 100nF cap0402 capacitor
 - C7: 100nF cap0402 capacitor
 - C5: 15pF cap0402 capacitor
 - R13: 1kΩ res0402 resistor
 - U4: W25Q128JVSIQ, soic8
 - U5: BMP390
 - R4: 4.7kΩ res0402 resistor
 - R5: 4.7kΩ res0402 resistor
 - U6: ICM-42688-P
 - U7: ADXL375
 - U8: SX1262
 - Y2: XTAL-32M-10PF
 - L3: L3, source_component
 - J3: U.FL-R-SMT-1(10)
 - U9: MAX-M10S
 - J5: U.FL-R-SMT-1(10)
 - LS1: PKLCS1212E4001-R1, pinrow2
 - D1: RGB-LED-CC, led5050
 - SW1: JS102011SCQN
 - R6: 100kΩ res0402 resistor
 - SW2: B3U-1000P, smdpushbutton
 - SW3: B3U-1000P, smdpushbutton
 - R10: 330Ω res0402 resistor
 - R11: 220Ω res0402 resistor
 - R12: 220Ω res0402 resistor
 - R9: 10kΩ res0402 resistor
 - J4: SWD-PADS
 - R7: 100kΩ res0402 resistor
 - R8: 100kΩ res0402 resistor
 - L1: L1, source_component

NET: U3_RUN
  - R9 pin2
  - SW3 A2
  - SW3 A1
  - U3 RUN

NET: U3_SWCLK
  - J4 SWCLK
  - U3 SWCLK

NET: U3_SWDIO
  - J4 SWDIO
  - U3 SWDIO

NET: U1_VDD
  - J1 pin10
  - J1 pin15
  - J1 pin7
  - J1 pin2
  - U1 VDD

NET: R1_pos
  - J1 pin3
  - R1 pin1

NET: R2_pos
  - J1 pin14
  - R2 pin1

NET: U1_PROG
  - U1 PROG
  - R3 pin1

NET: U3_USB_DP
  - J1 pin13
  - J1 pin4
  - U3 USB_DP

NET: U3_USB_DM
  - J1 pin12
  - J1 pin5
  - U3 USB_DM

NET: U3_QSPI_SCK
  - U3 QSPI_SCK
  - U4 CLK

NET: U3_QSPI_CS
  - SW2 A2
  - SW2 A1
  - U3 QSPI_CS
  - U4 CS

NET: U4_DI
  - U3 QSPI_D0
  - U4 DI

NET: U4_DO
  - U3 QSPI_D1
  - U4 DO

NET: U4_WP
  - U3 QSPI_D2
  - U4 WP

NET: U4_HOLD
  - U3 QSPI_D3
  - U4 HOLD

NET: U3_SDA
  - U3 SDA
  - U5 SDA
  - R4 pin1

NET: U3_SCL
  - U3 SCL
  - U5 SCL
  - R5 pin1

NET: U3_CS_IMU
  - U3 CS_IMU
  - U6 CS

NET: U3_CS_HIGHG
  - U3 CS_HIGHG
  - U7 CS

NET: U6_SCLK
  - U3 SPI_SCK
  - U6 SCLK
  - U7 SCLK
  - U8 SCK

NET: U3_SPI_MOSI
  - U3 SPI_MOSI
  - U6 SDI
  - U7 SDI
  - U8 MOSI

NET: U3_SPI_MISO
  - U3 SPI_MISO
  - U6 SDO
  - U7 SDO
  - U8 MISO

NET: U3_CS_RADIO
  - U3 CS_RADIO
  - U8 NSS

NET: U3_RADIO_BUSY
  - U3 RADIO_BUSY
  - U8 BUSY

NET: U3_RADIO_DIO1
  - U3 RADIO_DIO1
  - U8 DIO1

NET: U3_RADIO_NRESET
  - U3 RADIO_NRESET
  - U8 NRESET

NET: U3_RADIO_DIO2
  - U3 RADIO_DIO2
  - U8 DIO2

NET: U3_GNSS_TX
  - U3 GNSS_TX
  - U9 RXD

NET: U3_GNSS_RX
  - U3 GNSS_RX
  - U9 TXD

NET: U3_BUZZER
  - U3 BUZZER
  - LS1 IN

NET: U3_LED_R
  - U3 LED_R
  - R10 pin1

NET: D1_A_R
  - R10 pin2
  - D1 A_R

NET: U3_LED_G
  - U3 LED_G
  - R11 pin1

NET: D1_A_G
  - R11 pin2
  - D1 A_G

NET: U3_LED_B
  - U3 LED_B
  - R12 pin1

NET: D1_A_B
  - R12 pin2
  - D1 A_B

NET: U3_XOUT
  - R13 pin2
  - U3 XOUT

NET: U3_XIN
  - C4 pin1 (+)
  - U3 XIN
  - Y1 XA

NET: Y1_XB
  - C5 pin1 (+)
  - Y1 XB
  - R13 pin1

NET: U8_VREG
  - U8 VREG
  - L3 pin1 (+)

NET: U8_DCC_SW
  - L3 pin2 (-)
  - U8 DCC_SW

NET: U8_XTA
  - U8 XTA
  - Y2 XA

NET: U8_XTB
  - U8 XTB
  - Y2 XB

NET: U9_RF_IN
  - U9 RF_IN
  - J5 SIG

NET: L2_pos
  - U2 L1
  - L2 pin1 (+)

NET: L2_neg
  - U2 L2
  - L2 pin2 (-)

NET: VBAT
  - R7 pin1
  - C1 pin1 (+)
  - U2 VIN
  - J2 VBAT
  - U1 VBAT
  - U2 VINA
  - U2 EN

NET: U3_ARM
  - R6 pin1
  - SW1 COM
  - U3 ARM

NET: U3_VBAT_SENSE
  - R8 pin1
  - R7 pin2
  - U3 VBAT_SENSE

NET: U3_VREG_LX
  - U3 VREG_LX
  - L1 pin1 (+)

NET: VCORE
  - U3 DVDD3
  - U3 DVDD2
  - U3 DVDD1
  - U3 VREG_FB
  - L1 pin2 (-)

NET: V3V3
  - U3 VREG_VIN
  - U3 VREG_AVDD
  - U3 USB_OTP_VDD
  - U3 QSPI_IOVDD
  - U3 ADC_AVDD
  - U3 IOVDD6
  - U3 IOVDD5
  - U3 IOVDD4
  - U3 IOVDD3
  - U3 IOVDD2
  - U2 FB
  - R6 pin2
  - U9 V_BCKP
  - U9 V_IO
  - U9 VCC
  - U8 VDD_IN
  - U8 VBAT_IO
  - U8 VBAT
  - C12 pin1 (+)
  - C11 pin1 (+)
  - U7 RESV3
  - U7 VDDIO
  - U7 VS
  - C10 pin1 (+)
  - C9 pin1 (+)
  - C8 pin1 (+)
  - U6 VDDIO
  - U6 VDD
  - R5 pin2
  - R4 pin2
  - C7 pin1 (+)
  - C6 pin1 (+)
  - U5 CSB
  - U5 VDDIO
  - U5 VDD
  - U4 VCC
  - C3 pin1 (+)
  - U3 VDD
  - U2 VOUT
  - C2 pin1 (+)
  - R9 pin1

NET: GND
  - U3 VREG_PGND
  - U2 EPAD
  - U2 PGND
  - U2 PSSYNC
  - J5 GND2
  - J5 GND
  - Y2 CASE2
  - Y2 CASE1
  - C12 pin2 (-)
  - C11 pin2 (-)
  - C10 pin2 (-)
  - C9 pin2 (-)
  - C8 pin2 (-)
  - C7 pin2 (-)
  - C6 pin2 (-)
  - Y1 CASE2
  - Y1 CASE1
  - C5 pin2 (-)
  - C4 pin2 (-)
  - U5 SDO
  - R8 pin2
  - SW1 T1
  - D1 K_B
  - D1 K_G
  - D1 K_R
  - LS1 GND
  - U9 GND12
  - U9 GND10
  - U9 GND1
  - J3 GND2
  - J3 GND
  - U8 EPAD
  - U8 GND20
  - U8 GND8
  - U8 GND5
  - U8 GND2
  - U7 RESV11
  - U7 GND5
  - U7 GND4
  - U7 GND2
  - U6 RESV11
  - U6 RESV10
  - U6 RESV3
  - U6 RESV2
  - U6 RESV7
  - U6 GND
  - U5 VSS9
  - U5 VSS8
  - U5 VSS3
  - U4 GND
  - C3 pin2 (-)
  - U3 GND
  - C2 pin2 (-)
  - C1 pin2 (-)
  - U2 GND
  - J2 GND
  - R3 pin2
  - U1 VSS
  - R2 pin2
  - R1 pin2
  - J1 pin20
  - J1 pin19
  - J1 pin18
  - J1 pin17
  - J1 pin9
  - J1 pin16
  - J1 pin8
  - J1 pin1
  - J4 GND
  - SW3 B2
  - SW3 B1
  - SW2 B2
  - SW2 B1

COMPONENT_PINS:
J1 (USB4085-GF-A)
- pin1(A1): NETS(GND)
- pin2(A4): NETS(U1_VDD)
- pin3(A5): NETS(R1_pos)
- pin4(A6): NETS(U3_USB_DP)
- pin5(A7): NETS(U3_USB_DM)
- pin6(A8): NOT_CONNECTED
- pin7(A9): NETS(U1_VDD)
- pin8(A12): NETS(GND)
- pin9(B12): NETS(GND)
- pin10(B9): NETS(U1_VDD)
- pin11(B8): NOT_CONNECTED
- pin12(B7): NETS(U3_USB_DM)
- pin13(B6): NETS(U3_USB_DP)
- pin14(B5): NETS(R2_pos)
- pin15(B4): NETS(U1_VDD)
- pin16(B1): NETS(GND)
- pin17(SHELL00): NETS(GND)
- pin18(SHELL01): NETS(GND)
- pin19(SHELL10): NETS(GND)
- pin20(SHELL11): NETS(GND)

R1 (5.1kΩ res0402)
- pin1(anode, pos, left): NETS(R1_pos)
- pin2(cathode, neg, right): NETS(GND)

R2 (5.1kΩ res0402)
- pin1(anode, pos, left): NETS(R2_pos)
- pin2(cathode, neg, right): NETS(GND)

U1 (MCP73831)
- pin1(STAT): NOT_CONNECTED
- pin2(VSS): NETS(GND)
- pin3(VBAT): NETS(VBAT)
- pin4(VDD): NETS(U1_VDD)
- pin5(PROG): NETS(U1_PROG)

R3 (10kΩ res0402)
- pin1(anode, pos, left): NETS(U1_PROG)
- pin2(cathode, neg, right): NETS(GND)

J2 (S2B-PH-K-S)
- pin1(VBAT): NETS(VBAT)
- pin2(GND): NETS(GND)

U2 (TPS63001)
- pin1(VOUT): NETS(V3V3)
- pin2(L2): NETS(L2_neg)
- pin3(PGND): NETS(GND)
- pin4(L1): NETS(L2_pos)
- pin5(VIN): NETS(VBAT)
- pin6(EN): NETS(VBAT)
- pin7(PSSYNC): NETS(GND)
- pin8(VINA): NETS(VBAT)
- pin9(GND): NETS(GND)
- pin10(FB): NETS(V3V3)
- pin11(EPAD): NETS(GND)

L2
- pin1(anode, pos, left): NETS(L2_pos)
- pin2(cathode, neg, right): NETS(L2_neg)

C1 (10uF cap0805)
- pin1(pos, anode, left): NETS(VBAT)
- pin2(neg, cathode, right): NETS(GND)

C2 (22uF cap0805)
- pin1(pos, anode, left): NETS(V3V3)
- pin2(neg, cathode, right): NETS(GND)

U3 (RP2350A)
- pin1(VDD): NETS(V3V3)
- pin2(GPIO0): NOT_CONNECTED
- pin3(GPIO1): NOT_CONNECTED
- pin4(GPIO2): NOT_CONNECTED
- pin5(GPIO3): NOT_CONNECTED
- pin6(DVDD1): NETS(VCORE)
- pin7(SDA): NETS(U3_SDA)
- pin8(SCL): NETS(U3_SCL)
- pin9(GPIO6): NOT_CONNECTED
- pin10(GPIO7): NOT_CONNECTED
- pin11(IOVDD2): NETS(V3V3)
- pin12(GPIO8): NOT_CONNECTED
- pin13(LED_B): NETS(U3_LED_B)
- pin14(GPIO10): NOT_CONNECTED
- pin15(GPIO11): NOT_CONNECTED
- pin16(LED_G): NETS(U3_LED_G)
- pin17(ARM): NETS(U3_ARM)
- pin18(BUZZER): NETS(U3_BUZZER)
- pin19(LED_R): NETS(U3_LED_R)
- pin20(IOVDD3): NETS(V3V3)
- pin21(XIN): NETS(U3_XIN)
- pin22(XOUT): NETS(U3_XOUT)
- pin23(DVDD2): NETS(VCORE)
- pin24(SWCLK): NETS(U3_SWCLK)
- pin25(SWDIO): NETS(U3_SWDIO)
- pin26(RUN): NETS(U3_RUN)
- pin27(SPI_MISO): NETS(U3_SPI_MISO)
- pin28(CS_IMU): NETS(U3_CS_IMU)
- pin29(SPI_SCK): NETS(U6_SCLK)
- pin30(IOVDD4): NETS(V3V3)
- pin31(SPI_MOSI): NETS(U3_SPI_MOSI)
- pin32(CS_HIGHG): NETS(U3_CS_HIGHG)
- pin33(CS_RADIO): NETS(U3_CS_RADIO)
- pin34(RADIO_BUSY): NETS(U3_RADIO_BUSY)
- pin35(RADIO_DIO1): NETS(U3_RADIO_DIO1)
- pin36(GNSS_TX): NETS(U3_GNSS_TX)
- pin37(GNSS_RX): NETS(U3_GNSS_RX)
- pin38(IOVDD5): NETS(V3V3)
- pin39(DVDD3): NETS(VCORE)
- pin40(VBAT_SENSE): NETS(U3_VBAT_SENSE)
- pin41(RADIO_NRESET): NETS(U3_RADIO_NRESET)
- pin42(RADIO_DIO2): NETS(U3_RADIO_DIO2)
- pin43(GPIO29): NOT_CONNECTED
- pin44(ADC_AVDD): NETS(V3V3)
- pin45(IOVDD6): NETS(V3V3)
- pin46(VREG_AVDD): NETS(V3V3)
- pin47(VREG_PGND): NETS(GND)
- pin48(VREG_LX): NETS(U3_VREG_LX)
- pin49(VREG_VIN): NETS(V3V3)
- pin50(VREG_FB): NETS(VCORE)
- pin51(USB_DM): NETS(U3_USB_DM)
- pin52(USB_DP): NETS(U3_USB_DP)
- pin53(USB_OTP_VDD): NETS(V3V3)
- pin54(QSPI_IOVDD): NETS(V3V3)
- pin55(QSPI_D3): NETS(U4_HOLD)
- pin56(QSPI_SCK): NETS(U3_QSPI_SCK)
- pin57(QSPI_D0): NETS(U4_DI)
- pin58(QSPI_D2): NETS(U4_WP)
- pin59(QSPI_D1): NETS(U4_DO)
- pin60(QSPI_CS): NETS(U3_QSPI_CS)
- pin61(GND): NETS(GND)

C3 (100nF cap0402)
- pin1(pos, anode, left): NETS(V3V3)
- pin2(neg, cathode, right): NETS(GND)

Y1 (ABM8-272-T3)
- pin1(XA): NETS(U3_XIN)
- pin2(CASE1): NETS(GND)
- pin3(XB): NETS(Y1_XB)
- pin4(CASE2): NETS(GND)

C4 (15pF cap0402)
- pin1(pos, anode, left): NETS(U3_XIN)
- pin2(neg, cathode, right): NETS(GND)

C11 (100nF cap0402)
- pin1(pos, anode, left): NETS(V3V3)
- pin2(neg, cathode, right): NETS(GND)

C12 (1uF cap0603)
- pin1(pos, anode, left): NETS(V3V3)
- pin2(neg, cathode, right): NETS(GND)

C8 (100nF cap0402)
- pin1(pos, anode, left): NETS(V3V3)
- pin2(neg, cathode, right): NETS(GND)

C9 (2.2uF cap0603)
- pin1(pos, anode, left): NETS(V3V3)
- pin2(neg, cathode, right): NETS(GND)

C10 (10nF cap0402)
- pin1(pos, anode, left): NETS(V3V3)
- pin2(neg, cathode, right): NETS(GND)

C6 (100nF cap0402)
- pin1(pos, anode, left): NETS(V3V3)
- pin2(neg, cathode, right): NETS(GND)

C7 (100nF cap0402)
- pin1(pos, anode, left): NETS(V3V3)
- pin2(neg, cathode, right): NETS(GND)

C5 (15pF cap0402)
- pin1(pos, anode, left): NETS(Y1_XB)
- pin2(neg, cathode, right): NETS(GND)

R13 (1kΩ res0402)
- pin1(anode, pos, left): NETS(Y1_XB)
- pin2(cathode, neg, right): NETS(U3_XOUT)

U4 (W25Q128JVSIQ)
- pin1(CS): NETS(U3_QSPI_CS)
- pin2(DO): NETS(U4_DO)
- pin3(WP): NETS(U4_WP)
- pin4(GND): NETS(GND)
- pin5(DI): NETS(U4_DI)
- pin6(CLK): NETS(U3_QSPI_SCK)
- pin7(HOLD): NETS(U4_HOLD)
- pin8(VCC): NETS(V3V3)

U5 (BMP390)
- pin1(VDDIO): NETS(V3V3)
- pin2(SCL): NETS(U3_SCL)
- pin3(VSS3): NETS(GND)
- pin4(SDA): NETS(U3_SDA)
- pin5(SDO): NETS(GND)
- pin6(CSB): NETS(V3V3)
- pin7(INT): NOT_CONNECTED
- pin8(VSS8): NETS(GND)
- pin9(VSS9): NETS(GND)
- pin10(VDD): NETS(V3V3)

R4 (4.7kΩ res0402)
- pin1(anode, pos, left): NETS(U3_SDA)
- pin2(cathode, neg, right): NETS(V3V3)

R5 (4.7kΩ res0402)
- pin1(anode, pos, left): NETS(U3_SCL)
- pin2(cathode, neg, right): NETS(V3V3)

U6 (ICM-42688-P)
- pin1(SDO): NETS(U3_SPI_MISO)
- pin2(RESV2): NETS(GND)
- pin3(RESV3): NETS(GND)
- pin4(INT1): NOT_CONNECTED
- pin5(VDDIO): NETS(V3V3)
- pin6(GND): NETS(GND)
- pin7(RESV7): NETS(GND)
- pin8(VDD): NETS(V3V3)
- pin9(INT2): NOT_CONNECTED
- pin10(RESV10): NETS(GND)
- pin11(RESV11): NETS(GND)
- pin12(CS): NETS(U3_CS_IMU)
- pin13(SCLK): NETS(U6_SCLK)
- pin14(SDI): NETS(U3_SPI_MOSI)

U7 (ADXL375)
- pin1(VDDIO): NETS(V3V3)
- pin2(GND2): NETS(GND)
- pin3(RESV3): NETS(V3V3)
- pin4(GND4): NETS(GND)
- pin5(GND5): NETS(GND)
- pin6(VS): NETS(V3V3)
- pin7(CS): NETS(U3_CS_HIGHG)
- pin8(INT1): NOT_CONNECTED
- pin9(INT2): NOT_CONNECTED
- pin10(NC): NOT_CONNECTED
- pin11(RESV11): NETS(GND)
- pin12(SDO): NETS(U3_SPI_MISO)
- pin13(SDI): NETS(U3_SPI_MOSI)
- pin14(SCLK): NETS(U6_SCLK)

U8 (SX1262)
- pin1(VDD_IN): NETS(V3V3)
- pin2(GND2): NETS(GND)
- pin3(XTA): NETS(U8_XTA)
- pin4(XTB): NETS(U8_XTB)
- pin5(GND5): NETS(GND)
- pin6(DIO3): NOT_CONNECTED
- pin7(VREG): NETS(U8_VREG)
- pin8(GND8): NETS(GND)
- pin9(DCC_SW): NETS(U8_DCC_SW)
- pin10(VBAT): NETS(V3V3)
- pin11(VBAT_IO): NETS(V3V3)
- pin12(DIO2): NETS(U3_RADIO_DIO2)
- pin13(DIO1): NETS(U3_RADIO_DIO1)
- pin14(BUSY): NETS(U3_RADIO_BUSY)
- pin15(NRESET): NETS(U3_RADIO_NRESET)
- pin16(MISO): NETS(U3_SPI_MISO)
- pin17(MOSI): NETS(U3_SPI_MOSI)
- pin18(SCK): NETS(U6_SCLK)
- pin19(NSS): NETS(U3_CS_RADIO)
- pin20(GND20): NETS(GND)
- pin21(RFI_P): NOT_CONNECTED
- pin22(RFI_N): NOT_CONNECTED
- pin23(RFO): NOT_CONNECTED
- pin24(VR_PA): NOT_CONNECTED
- pin25(EPAD): NETS(GND)

Y2 (XTAL-32M-10PF)
- pin1(XA): NETS(U8_XTA)
- pin2(CASE1): NETS(GND)
- pin3(XB): NETS(U8_XTB)
- pin4(CASE2): NETS(GND)

L3
- pin1(anode, pos, left): NETS(U8_VREG)
- pin2(cathode, neg, right): NETS(U8_DCC_SW)

J3 (U.FL-R-SMT-1(10))
- pin1(ANT): NOT_CONNECTED
- pin2(GND): NETS(GND)
- pin3(GND2): NETS(GND)

U9 (MAX-M10S)
- pin1(GND1): NETS(GND)
- pin2(TXD): NETS(U3_GNSS_RX)
- pin3(RXD): NETS(U3_GNSS_TX)
- pin4(TIMEPULSE): NOT_CONNECTED
- pin5(EXTINT): NOT_CONNECTED
- pin6(V_BCKP): NETS(V3V3)
- pin7(V_IO): NETS(V3V3)
- pin8(VCC): NETS(V3V3)
- pin9(RESET_N): NOT_CONNECTED
- pin10(GND10): NETS(GND)
- pin11(RF_IN): NETS(U9_RF_IN)
- pin12(GND12): NETS(GND)
- pin13(LNA_EN): NOT_CONNECTED
- pin14(VCC_RF): NOT_CONNECTED
- pin15(VIO_SEL): NOT_CONNECTED
- pin16(SDA): NOT_CONNECTED
- pin17(SCL): NOT_CONNECTED
- pin18(SAFEBOOT_N): NOT_CONNECTED

J5 (U.FL-R-SMT-1(10))
- pin1(SIG): NETS(U9_RF_IN)
- pin2(GND): NETS(GND)
- pin3(GND2): NETS(GND)

LS1 (PKLCS1212E4001-R1)
- pin1(IN): NETS(U3_BUZZER)
- pin2(GND): NETS(GND)

D1 (RGB-LED-CC)
- pin1(A_B): NETS(D1_A_B)
- pin2(K_B): NETS(GND)
- pin3(A_R): NETS(D1_A_R)
- pin4(K_R): NETS(GND)
- pin5(A_G): NETS(D1_A_G)
- pin6(K_G): NETS(GND)

SW1 (JS102011SCQN)
- pin1(T1): NETS(GND)
- pin2(COM): NETS(U3_ARM)
- pin3(T3): NOT_CONNECTED

R6 (100kΩ res0402)
- pin1(anode, pos, left): NETS(U3_ARM)
- pin2(cathode, neg, right): NETS(V3V3)

SW2 (B3U-1000P)
- pin1(A1): NETS(U3_QSPI_CS)
- pin2(A2): NETS(U3_QSPI_CS)
- pin3(B1): NETS(GND)
- pin4(B2): NETS(GND)

SW3 (B3U-1000P)
- pin1(A1): NETS(U3_RUN)
- pin2(A2): NETS(U3_RUN)
- pin3(B1): NETS(GND)
- pin4(B2): NETS(GND)

R10 (330Ω res0402)
- pin1(anode, pos, left): NETS(U3_LED_R)
- pin2(cathode, neg, right): NETS(D1_A_R)

R11 (220Ω res0402)
- pin1(anode, pos, left): NETS(U3_LED_G)
- pin2(cathode, neg, right): NETS(D1_A_G)

R12 (220Ω res0402)
- pin1(anode, pos, left): NETS(U3_LED_B)
- pin2(cathode, neg, right): NETS(D1_A_B)

R9 (10kΩ res0402)
- pin1(anode, pos, left): NETS(V3V3)
- pin2(cathode, neg, right): NETS(U3_RUN)

J4 (SWD-PADS)
- pin1(SWCLK): NETS(U3_SWCLK)
- pin2(SWDIO): NETS(U3_SWDIO)
- pin3(GND): NETS(GND)

R7 (100kΩ res0402)
- pin1(anode, pos, left): NETS(VBAT)
- pin2(cathode, neg, right): NETS(U3_VBAT_SENSE)

R8 (100kΩ res0402)
- pin1(anode, pos, left): NETS(U3_VBAT_SENSE)
- pin2(cathode, neg, right): NETS(GND)

L1
- pin1(anode, pos, left): NETS(U3_VREG_LX)
- pin2(cathode, neg, right): NETS(VCORE)

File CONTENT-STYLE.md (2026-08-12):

# oApogee content style

Every page on this site is a set of instructions that someone will follow while
holding a soldering iron, or a set of numbers they will use to decide whether a
rocket is safe to fly. The documentation is the product. This file exists so
that a contributor writing page fourteen sounds like the person who wrote page
one, and so that the accuracy bar does not quietly drop over time.

Read the whole thing before writing. It is short.

## The name

The project is **oApogee**. Lowercase `o`, capital `A`, one word, no space, no
hyphen. Never "OApogee", "Open Apogee", "OpenApogee", or "o-Apogee". The logo
wordmark may be set in all lowercase as `oapogee`, but running prose always uses
oApogee.

**Never shorten it to "Apogee."** Apogee Components is the dominant retailer in
model rocketry and owns that word in this hobby completely. "The Apogee board"
or "Apogee recommends" would confuse readers and invite trademark friction.
There is no short form. It is oApogee in headings, in body copy, in image alt
text, in code comments, in repo names, in commit messages, and on the board
silkscreen.

The bare word "apogee" is fine when it means the physical event, the highest
point of a flight, which is what it means most of the time on this site. The
test is whether it names the project or the moment. "Apogee detection requires
three consecutive descending samples" is correct. "The Apogee firmware" is not.

The tiers are **oApogee Solo**, **oApogee Link**, and **oApogee Track**. Inside a
single section, after one full mention, "Solo", "Link", and "Track" alone are
fine, and are preferred in tables where the column already establishes context.

Pronunciation, "oh-APP-uh-jee", appears once, on the About page. The `o` stands
for open, stated once, on the About page, in one sentence. Neither belongs
anywhere else. Do not build a mythology around the name.

## The accuracy rule

This outranks every other rule in this file.

**Never invent a number.** Not a price, not a manufacturer part number, not a
mass, not a radio range, not a battery life, not a measured altitude, not a
current draw, not a print time. If there is no verified source and no
measurement from the maintainer, write a marker and move on:

```
TODO(verify): typical mass of the Solo build with a 150 mAh cell, measured on a
0.1 g scale, three assembled units.
```

Three markers, used precisely:

- `TODO(verify)` for a number, a price, a link, or a claim that needs a source
  or a measurement. Always say what evidence would close it.
- `TODO(confirm-on-hardware)` for a procedural step that cannot be checked until
  a physical board exists. The step may be written out in full, it is simply not
  trusted yet.
- `TODO(photo)` for an image slot, with a description of what the photo must
  show, not just "photo here".

Every marker is collected onto the site's status page when it builds. A marker
with no closing condition is not a marker, it is a shrug.

A page full of confident fabricated specs is worse than an empty page. Readers
in this hobby spend money and fly hardware over other people's heads based on
what a site like this tells them. An honest gap costs a reader five minutes. A
plausible wrong number costs them a rocket, or worse.

Rounded, clearly-labelled physics is not invention. "A 25 g payload on a C6-5
will cost you altitude" is a statement about how rocketry works. "A 25 g payload
on a C6-5 reduces apogee by 31 m" is a measurement, and needs OpenRocket output
or a real flight behind it.

## Voice

Second person, imperative in procedures.

> Solder the barometer first.

Not:

> The barometer should be soldered first.

Direct and unhyped. No "revolutionary", no "game-changing", no "unleash", no
"seamless".

**No minimisers in procedures.** "Just solder the header" and "simply flash the
firmware" tell a beginner whose hands are shaking that their difficulty is a
personal failing. Delete the word; the sentence is always better without it.

This bans a use, not a word. "You have just moved the centre of gravity" and
"check the total, not just the payload" are the ordinary senses of the word and
are fine. That is why this rule is not enforced by `make prose`: a checker that
flagged every "just" would produce mostly false positives and get ignored, which
is worse than a rule a human applies with judgement.

Confident about what works, honest about what does not. If the radio range
collapses in trees, say so with a number and say how the number was obtained.
The credibility of this site is the only asset it has.

Do not sell. The reader already decided to be here.

## Mechanics

- **Never use em dashes.** Use a comma, a colon, parentheses, or two sentences.
  This is checked in CI by `make prose`.
- No emoji in body content, ever. Status icons in the interface are a design
  decision, not a content one.
- No rhetorical questions as section openers.
- Short paragraphs. Three or four sentences is usually enough.
- Procedures are numbered lists. Reference material is tables. Neither is prose.
- Avoid bullet lists inside body prose. If a paragraph wants to become a list, it
  is usually reference material in the wrong section.
- Sentence case headings, always. "Static ports and why they matter", not
  "Static Ports And Why They Matter".
- Units get a space before them, "25 g", "902 MHz", "24 mm", except degrees and
  percent, "45deg", "20%". SI units, with imperial in parentheses where a US
  hobbyist buys the part in imperial, for example "24 mm (BT-50)".
- Motor designations are uppercase with the delay attached, "C6-5", "B6-4".
- Write "3D printed" and "3D printable", not "3d-printed".

## Layering, not dumbing down

Three readers, in priority order: the determined beginner, the educator, the
engineer. Never simplify a technical fact to serve the first reader. Layer it
instead.

The procedure comes first, in plain imperative steps a beginner can follow
without understanding why. The explanation follows, in a collapsible block or a
linked deep dive, for the reader who wants it. The engineer gets a reference
section with no hand-holding at all, reachable in one click from the top of the
page.

A beginner who is told what to do and offered the reason is respected. A
beginner who is given a simplified reason that is subtly wrong has been
patronised, and will discover it later.

## Checkpoints

Every build step that changes the state of the hardware ends with an observable
result. Not "the sensor should now work". Something the reader can see:

> You should see the status LED pulse green twice. The serial console should
> print a pressure between 95000 and 103000 Pa. If it prints 0, the sensor is
> not on the bus, go to Troubleshooting: the barometer never appears.

Write the failure branch next to the success branch. A beginner who sees the
wrong thing at step 7 needs to know at step 7, not after they have soldered
everything else on top of the mistake.

## Jargon

Define a term on first use on each page, briefly, in the sentence where it
appears. Then add it to `data/glossary.yaml` so it can be linked or hovered
consistently across the site.

The glossary entry is the long definition. The inline gloss is one clause.

> The payload sits above the static ports, the vent holes that let the
> barometer see outside air pressure.

## Safety language

Safety content is not a disclaimer and is not written in disclaimer voice. It is
procedural, specific, and states the actual failure mode rather than gesturing
at liability.

> A punctured LiPo cell can ignite minutes after the damage. Do not fly a cell
> that has been crushed, and do not put it back in a drawer.

Not:

> Users assume all risk associated with lithium polymer batteries.

Two hard boundaries appear anywhere they could plausibly be misread:

1. **oApogee is a passive instrumentation payload.** It does not fire ejection
   charges, control deployment, ignite motors, or command any pyrotechnic
   device. Any page that could imply otherwise is a bug.
2. **Part 15 and Part 97 are different legal regimes.** Never blur them. The
   unlicensed default and the amateur radio path are separately labelled and
   never mixed in the same procedure.

Link to primary sources for rules. NAR, Tripoli, the FAA, the FCC. Do not
paraphrase a safety code loosely and do not quote a version without a date.

## Frontmatter

Every prose page in `content/` carries this frontmatter:

```yaml
---
title: Safety and rules
description: One sentence, under 160 characters, used for the page meta description.
tier: all            # all | solo | link | track
difficulty: beginner # beginner | intermediate | advanced
time_estimate: null  # ISO-8601-ish human string, or null when not a procedure
updated: 2026-08-11  # ISO date, the day the content last actually changed
status: draft        # draft | needs-review | verified
---
```

`status` is a promise to the reader, so it is a promise about process:

- `draft`, written, not checked by anyone.
- `needs-review`, the author believes it is right and wants a second pair of
  eyes on the technical content.
- `verified`, a human with the relevant expertise has checked every number and
  every step on real hardware. Nothing reaches `verified` while it still
  contains a `TODO(verify)` or a `TODO(confirm-on-hardware)`.

Only the maintainer moves a page to `verified`.

## Content lives outside prose when it renders more than once

The bill of materials, the glossary, the preflight checklist, the tier
comparison, and the troubleshooting index are structured data in `data/`, in
YAML. They render into the site, into printable sheets, and into the repository
README. A table hand-written inside a Markdown page will drift from the one next
to it, and there is no way to check that it has not.

Prose pages reference the data. They do not restate it.

## Markdown stays portable

Plain CommonMark plus GFM tables. No framework components in Markdown, no MDX
imports, no HTML beyond `<details>` and `<summary>` for the layering pattern.
The content in this repository should survive being read on GitHub, piped
through pandoc, or printed. That constraint is what keeps it a documentation
project rather than a website with words in it.

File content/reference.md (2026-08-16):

---
title: Reference
description: Schematic, pinout, mechanical drawings, wire format specifications, and errata. No hand-holding.
tier: all
difficulty: advanced
time_estimate: null
updated: 2026-08-11
status: draft
---

# Reference

Everything an engineer needs, with the explanation stripped out. If you want the
reasoning, it is on the page that owns each subject.

## Specifications

- [Telemetry packet format](/reference/telemetry-packet), version 1. The
  downlink wire format: byte layout, packet types, field encodings, CRC, and
  receiver conformance rules.
- [Onboard log format](/reference/log-format), version 1. Directory layout, the
  self-describing manifest, fixed-width record layouts, and reader conformance
  rules.

Both are published so that third parties can write their own tools without
reverse engineering anything, and both carry a reference implementation.

## System block diagram

The generated system diagram is on the [bill of materials](/bom) page. It is
rendered from `data/system.yaml`, whose nodes reference part identifiers in
`data/bom.yaml`, and the build fails if the committed diagram stops matching the
data it was drawn from.

## Flight state machine

| Value | State | Transitions to | On |
|---|---|---|---|
| 0 | `PAD_IDLE` | `ARMED` | Operator arms the payload |
| 1 | `ARMED` | `BOOST` | Sustained upward acceleration, held for N samples |
| 2 | `BOOST` | `COAST` | Acceleration crosses zero, burnout |
| 3 | `COAST` | `APOGEE` | Altitude decreasing across N consecutive samples |
| 4 | `APOGEE` | `DESCENT` | Sustained descent confirmed |
| 5 | `DESCENT` | `LANDED` | Altitude and acceleration quiet for a sustained period |
| 6 | `LANDED` | none | Terminal until power cycle |

The same enumeration appears in the firmware, the log format, and the packet
format. Values 7 to 255 are reserved.

**There is no transition back to `PAD_IDLE`.** Moving the arming switch to safe
after the payload has armed does not disarm it, and that is deliberate rather
than unfinished: the switch is a mechanical contact on a vehicle that vibrates,
and a state machine that dropped out of `ARMED` on a momentary open would lose
the pre-arm buffer and the settled pressure reference at the worst possible
moment. Arming is a latch. To genuinely return to `PAD_IDLE` after a scrubbed
countdown, press reset or cycle the power, then arm again once the reference has
settled.

This costs nothing in safety, because oApogee is a passive payload. Disarming
does not make anything safe that was dangerous: no charge is fired, no
deployment is controlled, no motor is ignited. What arming changes is whether
the payload is recording.

TODO(verify): every threshold marked N above is unset. They must come from
measured sensor noise on real hardware, not from intuition, and each carries its
own verification note in `data/flight-phases.yaml`.

## Flags

Identical bit assignments in the packet header and in each log record.

| Bit | Mask | Name | Meaning when set |
|---|---|---|---|
| 0 | 0x01 | `GNSS_FIX` | Position fix available |
| 1 | 0x02 | `HIGH_G` | High-g accelerometer present and healthy |
| 2 | 0x04 | `BARO_FAULT` | Barometer failed or implausible |
| 3 | 0x08 | `IMU_FAULT` | IMU failed or implausible |
| 4 | 0x10 | `LOG_FULL` | Storage full, logging stopped |
| 5 | 0x20 | `LOW_BATT` | Battery below threshold |
| 6 | 0x40 | `SIM` | Bench test or simulation, not a flight |
| 7 | 0x80 | reserved | Transmit 0, ignore on receive |

## Parts

Manufacturer part numbers, roles, tier membership, substitutes, and the
reasoning behind each choice are on the [bill of materials](/bom), generated
from `data/bom.yaml`.

## Schematic and PCB

All of it is on the [schematic page](/reference/schematic): the drawing, the
netlist as text, the routed PCB, the assembly view, a KiCad schematic and the
circuit JSON.

The fabrication package is not there, and that page says why rather than this
one. `make fab` refuses to write Gerbers while the board has an open blocker,
and it currently has two, so publishing them would be publishing a board that
does not work. The list is generated from the check on every build, so it is
right on the day you read it rather than on the day somebody wrote it.

Everything there is generated from `hardware/oapogee.tsx` by `make hw`, and the
build fails when a committed artifact stops matching the source it came from.

## Pinout

The microcontroller's pin assignment is fixed and is in the circuit source. The
60 pins of the package were transcribed from the Raspberry Pi datasheet, and
signals sit on GPIOs their peripherals can actually reach: I2C0 on GPIO4 and
GPIO5, SPI0 on GPIO16, GPIO18 and GPIO19, UART1 on GPIO24 and GPIO25, and the
battery sense on GPIO26, which is the one wired to the ADC.

TODO(confirm-on-hardware): the other fourteen packages have pin numbering that
has not been checked against a datasheet. A wrong pin number is invisible in a
schematic and in a render, and shows up as a board that does not work, so
confirm every package by hand before ordering.

## Mechanical

The board outline is set in the circuit source and in `data/mechanical.yaml`,
and the build fails if the two disagree, because the printed enclosure is
generated from it. The dimensions themselves are not repeated here: they have
changed twice as the layout grew, and a third copy in prose is a third thing to
forget. The [Mounting](/mounting) page renders them from the data, along with
the overall size of each printed part measured off its own model.

The sled and pod are published as OpenSCAD source alongside their STLs, with
every dimension and where it came from, on the [Mounting](/mounting) page.

TODO(confirm-on-hardware): mounting hole positions and diameters, connector
positions, and the maximum component height on each side. All four need a
fabricated board and a pair of calipers, and the enclosure's board pocket is
sized from provisional figures until they exist.

## Firmware

TODO(confirm-on-hardware): configuration file reference, serial command
reference, and the self-test output format.

## Errata

None recorded, because nothing exists to have errata against.

When hardware ships, this section carries every known defect, with the revision
affected and the workaround. Errata for a flight computer are safety
information: if a firmware release changes an apogee detection threshold,
somebody flying the previous build needs a way to find that out.

## Changelog

Every change and decision so far is in the [changelog](/changelog), rendered
from `CHANGELOG.md`. Nothing has been released yet, so every entry sits under
Unreleased. Errata will appear there too.

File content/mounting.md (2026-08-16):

---
title: Mounting
description: The internal sled and the external pod, static port sizing and placement, the stability check you must do, and what payload mass costs you in altitude.
tier: all
difficulty: intermediate
time_estimate: null
updated: 2026-08-11
status: draft
---

# Mounting

This page is where the claim that oApogee attaches to any model rocket either
becomes true or does not. It covers two form factors, the vent holes without
which the barometer is useless, and the stability check that keeps the rocket
flying straight with a payload on it.

## Two form factors

### Form A: the internal sled

A printed sled that slides into a payload bay, cut for the bore of a BT-55 body
tube by default.

The two form factors are sized for different rockets on purpose. The pod straps
to the outside of a tube as small as a BT-50, which is the whole point of it:
your rocket needs no payload bay. The sled needs a rocket that has one, and a
rocket with a payload section is a bigger rocket. Sizing the sled for a BT-50
as well produced a part with a sliver of rail on each side of the board, which
a slicer will happily emit and a landing will happily break. The board has grown
since, and no longer fits that bore at all.

A coupler is narrower than the tube it joins, so it is not the same fit either.
Measure yours and re-render with that bore rather than assuming.

Use this if your rocket already has a payload section. It is the lighter and
lower-drag option, it does not change the outside of the airframe at all, and it
puts the payload on the vehicle centreline where its mass has the least awkward
effect.

Its limitation is that it only works on rockets that have somewhere to put it.

### Form B: the external pod

A streamlined printed fairing that straps or tapes to the outside of the body
tube, in the manner of a rail button pod.

**This is the one that makes the "any rocket" claim true.** It requires no
modification to the airframe, it works on a rocket you already own and like, and
it comes off again afterwards. Nothing gets drilled, cut, or glued to a rocket
you care about.

It also costs you something, and this page is the wrong place to be shy about
it. A pod on the outside adds drag, adds asymmetric drag, and moves both the
centre of gravity and the centre of pressure in ways that depend entirely on
where you put it. On a small light rocket that is not a rounding error. "No
modification to the airframe" is not the same as "no effect on the rocket."

TODO(verify): measure the altitude penalty of the pod against the same rocket
and motor flown without it, several times each, and publish both the mean and
the spread. This is the number that decides whether the pod is worth it and it
should come from flights rather than from simulation alone.

### Printed files

Both form factors are below, as OpenSCAD source and as rendered STLs, with every
dimension they are built from and where each one came from.

The pod is two parts. A single-piece pod has a cavity that opens somewhere and
every choice is bad: upward leaves the payload uncovered, downward onto the tube
leaves nothing holding the board, and neither prints, because the pod is convex
on top and concave underneath so no orientation puts a flat face on the bed.
Split at the top of the cell, both halves have a large flat face, both print it
face down with no supports, and the saddle ends up facing upward where a concave
surface costs nothing.

TODO(confirm-on-hardware): the board outline is a guess and it is the most
important input to both parts. Fix it in the PCB layout, measure a fabricated
board, and update `data/mechanical.yaml`. Until then these print as fit checks.

## Static ports

A barometric sensor inside a sealed tube measures the tube. It produces a smooth,
confident, entirely fictional altitude curve, which is worse than an obvious
failure because nothing about it looks wrong.

Static ports are the holes that let the sensor see outside air. Getting them
right is the difference between a flight profile and a fiction.

### The rules

1. **More than one hole, evenly spaced around the circumference.** A single hole
   makes the reading depend on which way that hole faces relative to the airflow.
   Three or four spaced evenly average out yaw and roll.
2. **Away from discontinuities.** Keep them clear of the nose cone shoulder, fin
   roots, and any step in the airframe. Air near those places is disturbed by the
   airframe, and disturbed air is not ambient.
3. **Beside the sensor, not far from it.** The volume the sensor shares with the
   ports should be small and directly connected.
4. **Deburr them.** A raised lip around a drilled hole trips the airflow over it,
   which is exactly the thing the port exists to avoid. Take the burr off with a
   knife or a larger drill bit turned by hand.
5. **Check them on every flight day.** Paint, glue, tape and swarf all block
   ports, and a blocked port is on the preflight checklist for that reason.

### Sizing

TODO(verify): publish the port diameter and count oApogee recommends, along with
the reasoning that produced them. The rule of thumb in hobby rocketry relates
total vent area to the enclosed volume, and this site should state the specific
rule it is using, cite where it comes from, and show the arithmetic for the
standard sled and pod volumes rather than quoting a number with no derivation.
Then confirm it by flying the same rocket with two different port
configurations and comparing.

Until that is measured, this page will not print a number. A confident wrong
port size produces confident wrong altitudes for everybody who follows it.

## Stability, which is a safety issue

**Re-simulate your rocket in OpenRocket with the payload mass and position
included, before you fly it.**

Not after. Not on the second flight. A rocket that has flown well ten times
tells you nothing about how it flies with a payload in a new place, because the
thing that makes a rocket stable is the relationship between two points that you
have just moved.

A rocket is stable when its centre of pressure sits behind its centre of
gravity. Adding mass moves the centre of gravity, and which way depends entirely
on where the payload goes relative to the existing balance point: forward of it
moves the centre of gravity forward, aft of it moves it backwards. Too far back
and the rocket is unstable, which does not mean it flies badly, it means it
flies sideways.

Too far forward has a cost too. A large stability margin makes the rocket
weathercock hard into the wind, which loses altitude and can send it downrange
over people.

The external pod makes this easier to get wrong than the sled, because the pod
can be strapped anywhere along the tube and the convenient place is not always
the right one.

### What to aim for

TODO(verify): state the caliber margin oApogee recommends, quoted from NAR or
Tripoli guidance with a citation rather than asserted from memory. This is a
safety number and it does not get a rule of thumb from an anonymous website.

### A worked example

TODO(verify): work a complete example. Take a named, commonly available kit,
state its published stability margin unloaded on a specific motor, then show the
same rocket in OpenRocket with an oApogee pod at two different positions, one
sensible and one badly chosen, with the resulting margins and what each means.
Include the OpenRocket file so a reader can open it rather than trusting a
screenshot.

## Mass budget

Every gram you add is altitude you do not get. How much depends on the motor:
the smaller the motor, the more a fixed payload mass costs you as a fraction.

TODO(verify): publish a table of apogee against payload mass for A, B, C, D and
E motors on a representative airframe, generated from OpenRocket and checked
against at least one real flight per motor class. A reader deciding between Solo
and Track deserves to see what the extra mass costs them before they order.

The qualitative shape, which is safe to state without measuring: a payload that
is a small fraction of the total liftoff mass costs little; one that is a
significant fraction costs a lot; and on the smallest motors, a payload can be a
large enough fraction that the flight is not worth doing. That last case is real
and it is why Solo exists.

## Why the hardware is bright yellow

The board soldermask and the printed pod are hi-vis yellow or orange. This is a
recovery decision, not a styling one.

A payload that comes off the rocket, or a rocket that lands in tall grass, is
found by eye. A bright object in a green or brown field is visible from many
times the distance a black or white one is, and the walk to recover it is
shorter and more likely to succeed. Every recovery aid on this board exists
because a payload you cannot find is a payload whose data you do not have.

Print your pod in the brightest filament you own. Do not print it black because
it looks better on the rocket.

## Securing the payload

Two things must not move: the board, and the cell.

The board moving means joints flex under boost, and a flexing joint fails at the
worst moment. The cell moving is worse: a lithium cell that shifts under
acceleration and lands on a solder joint is a short circuit inside a sealed
plastic box.

Route the wires so that closing the enclosure cannot pinch them. Then shake the
closed assembly hard and listen. Anything you can hear moving in your hand moves
far harder under boost, where the acceleration is many times what your arm can
produce.

## Antennas

A Link or Track payload has one antenna, a Track payload has two, and both plug
into sockets rather than being soldered down. That is deliberate: where an
antenna goes is a question about your airframe, not about the board, and the two
antennas want opposite things.

**The radio antenna wants to be away from metal and along the airframe.** It is
transmitting to somebody standing on the ground, so the useful direction is
sideways and down, not up. A quarter-wave wire run along the inside of a body
tube is the usual answer and costs nothing.

**The GNSS antenna wants to see sky.** It is receiving from satellites overhead,
which puts it in direct conflict with the radio antenna's preferences and with
most of the places a payload physically fits. A patch antenna is directional and
needs to point up; a helical is less fussy and worse in the open.

Two constraints that decide more than the antenna choice does:

- **Airframe material.** Cardboard and most plastics are close to transparent at
  both frequencies. Carbon fibre is not: it is conductive, and a payload sealed
  inside a carbon tube is a payload inside a Faraday cage. Metal is worse.
- **Distance from each other.** A transmitter and a receiver a few centimetres
  apart share a small volume, and the transmitter is many orders of magnitude
  louder than the satellites the receiver is listening for.

TODO(verify): this section gives directions, not distances, because no oApogee
payload has flown. What closes it is a range test with the antenna in the
positions people will actually use, and a time to first fix measured inside a
real airframe rather than on a bench. Both are named on the antenna rows in the
[bill of materials](/bom).

## Fitting to the rail

Check that the rocket still slides freely on the launch rail with the pod
fitted. An external pod is the most common thing to catch on a rail button or a
launch lug, and discovering it at the pad with a queue behind you is a bad time
to find out.

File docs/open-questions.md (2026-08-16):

# Open questions

Design decisions that are not settled, with the arguments on each side. Kept in
the open because a project that only publishes its conclusions is asking to be
trusted rather than checked, and because most of these are questions somebody
with more flying experience than us can answer in a sentence.

Numbers that need measuring rather than deciding are not here. Those live as
markers in the content files and are listed at
[oapogee.space/status](https://oapogee.space/status).

Settled decisions and their reasoning move to [CHANGELOG.md](../CHANGELOG.md).

## Should the high-g accelerometer be tied to a tier or to a motor class

Currently it is specified at Link and above, which is where the original design
brief put it.

That is arguably wrong. Link is defined by adding a radio, and whether a general
purpose IMU saturates during boost depends on the motor, not on whether there is
a transmitter on the board. A Solo builder flying a D or an E motor has exactly
the same saturation problem, and Solo is the tier whose entire value is the
logged flight profile.

**Decided: optional populate at every tier, including Solo.**
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

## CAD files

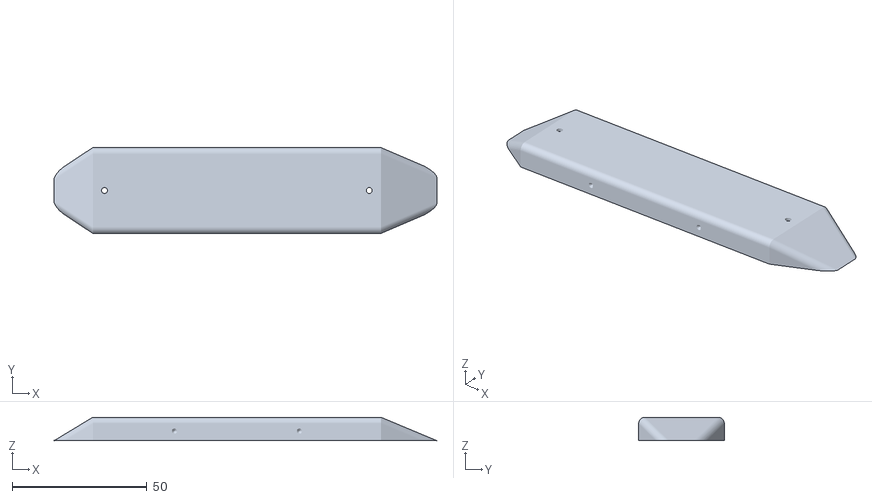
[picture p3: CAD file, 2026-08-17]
apps/web/public/hardware/mechanical/oapogee-pod-cap.stl
141.9 x 31.8 x 8.70

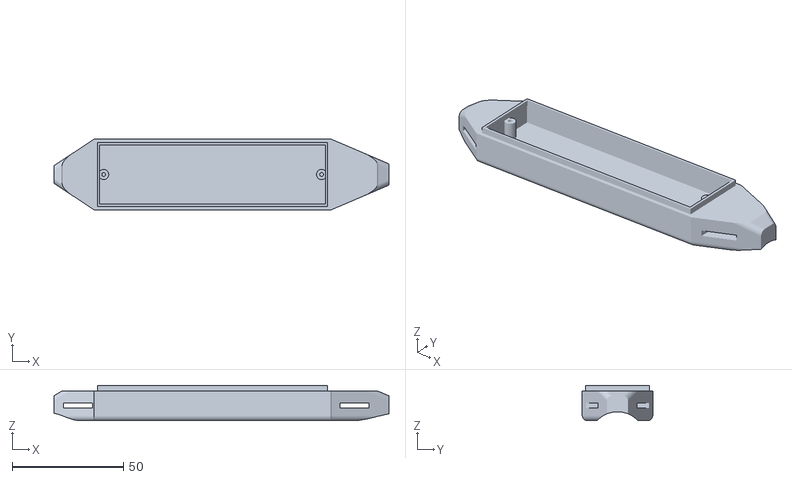
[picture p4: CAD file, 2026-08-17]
apps/web/public/hardware/mechanical/oapogee-pod-base.stl
150.8 x 31.8 x 15.9

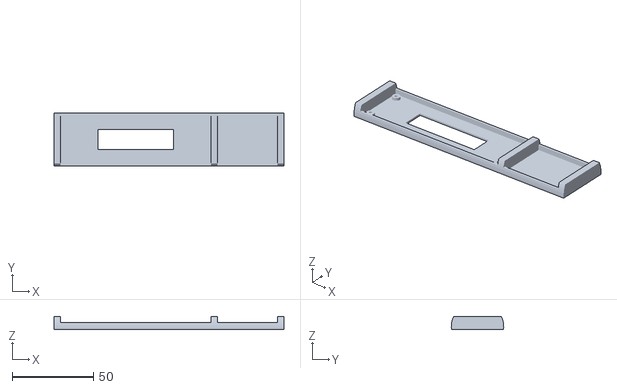
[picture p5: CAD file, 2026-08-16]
apps/web/public/hardware/mechanical/oapogee-sled.stl
141.4 x 32.3 x 7.80

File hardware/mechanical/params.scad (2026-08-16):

// GENERATED by tools/gen-mechanical.mjs from data/mechanical.yaml. Do not edit.
//
// Change a dimension in data/mechanical.yaml and run `make mech`. Editing this
// file directly means the site and the model disagree, and the site is what a
// builder reads before ordering.
//
// 8 of these 28 dimensions are provisional: not measured, not
// sourced, and they will change. They are marked PROVISIONAL below. A part
// printed from them is a fit-check, not a finished component.

// --------------------------------------------------------------------------
// BOARD
// The payload PCB. Nothing here is measured, because nothing has been
// fabricated. These are the constraints the board will be designed to meet
// rather than observations of one that exists.

// Long dimension of the PCB outline. [PROVISIONAL]
//   TODO(confirm-on-hardware): mirrors the board element in
//   hardware/oapogee.tsx, which is the closest thing to an outline that exists.
//   check-data fails if the two disagree, because they did: this file said 55 by
//   20 while the circuit source said 60 by 22, and the enclosure was being built
//   for a board nothing else described. Neither is measured until a board is
//   fabricated and put on calipers.
board_length = 92;  // mm

// Short dimension of the PCB outline. [PROVISIONAL]
//   TODO(confirm-on-hardware): as board_length, mirrors hardware/oapogee.tsx.
//   This is the dimension the sled is tightest on, and it is why the board has
//   only ever grown in one direction. What is left for the sled rail on each
//   side is half of (tube_id minus this width minus fit_clearance), and the rail
//   cannot usefully be thinner than floor_thickness, which is what the printer
//   can lay down and have hold together. Widening the board eats that allowance
//   twice over, once on each side, while lengthening it costs nothing at all. So
//   when the layout has needed room it has been given length, and this number
//   moves only if the tube does.
board_width = 28;  // mm

// PCB thickness. [standard]
//   The default thickness for two-layer FR-4 at every prototype fabricator, and
//   what the board will be ordered as. This one is safe to build against.
board_thickness = 1.6;  // mm

// Mounting hole diameter, M2 close clearance. [standard]
//   ISO 273 close-fit clearance hole for an M2 screw. The sled posts are sized
//   from this rather than the other way round.
mount_hole_dia = 2.2;  // mm

// Centre of each mounting hole, in from both board edges. [PROVISIONAL]
//   TODO(confirm-on-hardware): set by the PCB layout once the outline and the
//   keepouts around the USB connector and the antenna are fixed.
mount_hole_inset = 3;  // mm

// Tallest component above the board. [PROVISIONAL]
//   TODO(confirm-on-hardware): measure the assembled board. Likely set by the
//   USB-C receptacle or the buzzer, both of which are among the tallest parts in
//   the bill of materials.
comp_height_top = 4;  // mm

// Tallest component below the board. [PROVISIONAL]
//   TODO(confirm-on-hardware): measure the assembled board. Sets how far the
//   board stands off the sled floor, so a wrong value here means the board does
//   not sit flat.
comp_height_bottom = 1.5;  // mm

// --------------------------------------------------------------------------
// CELL
// The lithium pouch. Sized for the cell cavity to hold it without compression,
// because a pouch cell under sustained pressure is a hazard.

// Cell cavity length. [PROVISIONAL]
//   TODO(verify): the bill of materials does not name a specific cell yet, and
//   cannot until the current draw of each tier has been measured. These
//   dimensions are for a common 1S pouch in the 150 to 250 mAh range and will be
//   replaced with the dimensions of the cell actually chosen.
cell_length = 35;  // mm

// Cell cavity width. [PROVISIONAL]
//   TODO(verify): as cell_length, the cell is not chosen yet and cannot be until
//   per-tier current draw has been measured.
cell_width = 20;  // mm

// Cell cavity depth. [PROVISIONAL]
//   TODO(verify): as cell_length. Must include the protection circuit, which
//   sits at one end of the pouch and is often thicker than the pouch itself.
cell_thickness = 6;  // mm

// Slack added around the cell on every face. [practice]
//   A pouch cell must not be a press fit. Cells swell slightly with age and
//   charge state, and a cavity that grips one is applying sustained pressure to
//   a lithium pouch. Retention is the strap's job, not the cavity's.
cell_squeeze = 0.6;  // mm

// --------------------------------------------------------------------------
// AIRFRAME
// The rocket the payload attaches to. These are the parameters a builder
// changes for their own vehicle, and the reason the source is published rather
// than only the STLs.

// Body tube outside diameter the pod saddle is cut for. [standard]
//   Estes BT-50, 0.976 in from the published catalogue dimension. This is the
//   one parameter most builders will change, which is the whole reason the
//   source is published. Measure your own tube: paper tube stock varies with
//   humidity and between production runs, and the saddle is the surface where
//   that variation shows up as a rock.
tube_od = 24.8;  // mm

// Body tube inside diameter the sled is sized for. [standard]
//   Estes BT-55, 1.283 in from the published catalogue dimension. Deliberately a
//   different airframe from tube_od above, because the two form factors suit
//   different rockets and pretending otherwise produced a part that did not
//   work. When the sled was first drawn this was an argument about rail
//   thickness: a BT-50 bore is 24.13 mm and the board was narrow enough to sit
//   inside it with a sliver of rail on each side, printable in the sense that a
//   slicer would emit it and nothing in the sense of a part that survives a
//   landing. The board has grown since, and the argument is now arithmetic
//   rather than judgement: board_width exceeds a BT-50 bore, so the board does
//   not enter that tube at all. The pod exists so a small tube needs no payload
//   bay; a sled needs a rocket that has one, and a rocket with a payload section
//   is a bigger rocket. Measure your own tube and re-render either way.
tube_id = 32.59;  // mm

// --------------------------------------------------------------------------
// POD
// The external fairing, Form B.

// Fairing wall thickness. [derived]
//   Four perimeters at a 0.4 mm nozzle. Chosen as a multiple of the extrusion
//   width so the slicer produces solid wall rather than a thin gap it has to
//   fill badly.
pod_wall = 1.6;  // mm

// Length of the tapered leading fairing. [practice]
//   A taper long enough to keep the flow attached, kept short because every
//   millimetre is mass and drag on the outside of somebody's rocket. The
//   altitude penalty this trades against is unmeasured, and the Mounting page
//   says so.
pod_nose_len = 18;  // mm

// Length of the tapered trailing fairing. [practice]
//   Longer than the nose. A blunt tail separates the flow and separation costs
//   far more drag than a blunt leading edge does.
pod_tail_len = 26;  // mm

// Width of each strap slot. [standard]
//   Clears 1/2 in hook-and-loop strap, the common size, and comfortably clears a
//   3.6 mm cable tie. Two slots, so the pod is held at both ends.
strap_slot_width = 13;  // mm

// Height of each strap slot. [practice]
//   Passes doubled hook-and-loop without forcing it.
strap_slot_height = 2.4;  // mm

// How far the body tube sinks into the underside of the pod. [practice]
//   Deep enough that the pod cannot rock on the tube, shallow enough that the
//   pod does not stand proud of it any further than it must. The saddle is cut
//   for tube_od, so changing the tube diameter reshapes this surface.
pod_saddle_depth = 4;  // mm

// Slack between the board and the cell inside the cavity. [practice]
//   Keeps the board off the pouch. Foam or tape fills it on assembly.
pod_cavity_gap = 1;  // mm

// Cavity length added at each end for the screw bosses. [practice]
//   The cap screws into two bosses standing inside the cavity, clear of the
//   board at both ends. This is the room they need.
pod_boss_pad = 5.5;  // mm

// How far the base wall continues up inside the cap. [practice]
//   A spigot, so the two halves locate on each other rather than on the two
//   screws. Screws through an unaligned joint bend the cap instead of closing
//   it.
pod_lip_height = 2.5;  // mm

// Number of static port pilot marks. [derived]
//   From the rule on the Mounting page: more than one, evenly spaced, to average
//   out yaw and roll. Four is the count that page recommends. The diameter is
//   deliberately not published here, and the pod prints dimples rather than
//   holes for that reason.
port_count = 4;

// --------------------------------------------------------------------------
// SLED
// The internal carrier, Form A.
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

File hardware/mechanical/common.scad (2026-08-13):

// Shapes both printed parts share.
//
// Everything here is driven by params.scad, which is generated from
// data/mechanical.yaml. No dimension is written in this file, on purpose: a
// number typed into geometry is a number the site cannot see and a reviewer
// cannot check the provenance of.

include <params.scad>

$fn = 64;

// The board and the cell, as solids to subtract. Rendered on their own by
// fit.scad so you can see what the cavity is holding.
module board_envelope(clearance = 0) {
    c = clearance;
    translate([-c, -board_width / 2 - c, -c])
        cube([board_length + 2 * c, board_width + 2 * c, board_thickness + 2 * c]);
}

module board_components(clearance = 0) {
    c = clearance;
    // Component keepout above and below, inset from the edge so the envelope
    // stays the thing that sets the fit.
    translate([-c, -board_width / 2 - c, board_thickness])
        cube([board_length + 2 * c, board_width + 2 * c, comp_height_top + c]);
    translate([-c, -board_width / 2 - c, -comp_height_bottom - c])
        cube([board_length + 2 * c, board_width + 2 * c, comp_height_bottom + c]);
}

module cell_envelope(clearance = 0) {
    c = clearance + cell_squeeze;
    translate([-c, -(cell_width + 2 * c) / 2, -c])
        cube([cell_length + 2 * c, cell_width + 2 * c, cell_thickness + 2 * c]);
}

// The four board mounting holes, as posts or as holes depending on what is
// wrapped around them.
module mount_points(d, h) {
    for (x = [mount_hole_inset, board_length - mount_hole_inset])
        for (y = [-board_width / 2 + mount_hole_inset, board_width / 2 - mount_hole_inset])
            translate([x, y, 0]) cylinder(d = d, h = h);
}

// A rounded slab used as a station in a hull. Hulling several of these along X
// gives a smooth streamlined body without a surface of revolution, which is
// what a pod wants: it has to be wide and flat, not round.
module station(x, w, h, r) {
    translate([x, 0, 0])
        hull()
            for (sy = [-1, 1])
                for (sz = [0, 1])
                    translate([0, sy * (w / 2 - r), sz * (h - 2 * r) + r])
                        rotate([0, 90, 0])
                            cylinder(r = r, h = 0.01, center = true);
}

// The static port pilot marks.
//
// Shallow cones, not holes. The Mounting page will not publish a port diameter
// until it has been derived from the enclosed volume and confirmed by flying
// two configurations, and a model that shipped a default would make that
// refusal false in the one place a builder acts on it. So the pod tells you
// where to drill, which is known, and not how big, which is not.
//
// Set port_dia on the command line to bore them for real:
//   openscad -D port_dia=3 -o pod.stl pod.scad
module port_mark(depth) {
    if (port_dia == undef) {
        // Cone rather than cylinder: a drill bit centres itself in a cone, and
        // a mark you cannot start a bit in is decoration.
        rotate([0, 90, 0]) cylinder(r1 = depth, r2 = 0, h = depth);
    } else {
        assert(port_dia > 0, "port_dia must be positive");
        rotate([0, 90, 0]) cylinder(d = port_dia, h = depth * 4, center = true);
    }
}

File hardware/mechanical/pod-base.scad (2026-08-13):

// Form B, lower half: carries the cell, takes the straps, sits on the tube.
//
//   openscad -o oapogee-pod-base.stl pod-base.scad
//   openscad -D tube_od=41.6 -o base-bt60.stl pod-base.scad   a different airframe
//
// Print the flat split face down, no supports. That puts the saddle facing
// upward, where a concave surface costs nothing, and gives the first layer the
// largest flat face on the part.

include <pod-shape.scad>

difference() {
    union() {
        difference() {
            intersection() {
                pod_outer();
                below_split();
            }
            saddle();
            cavity();
            strap_slots();
        }
        bosses();
        lip();
    }
    boss_pilots();
}

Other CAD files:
hardware/mechanical/pod-cap.scad
hardware/mechanical/pod-shape.scad
hardware/mechanical/sled.scad

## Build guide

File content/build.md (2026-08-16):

---
title: Build guide
description: Step by step assembly of an oApogee payload, with an observable checkpoint at every stage and a link to the failure branch when a checkpoint does not pass.
tier: all
difficulty: intermediate
time_estimate: null
updated: 2026-08-11
status: draft
---

# Build guide

Every step here ends with something you can see, hear, or measure. If you see
the wrong thing, the step tells you where to go before you build anything on top
of the mistake.

**This guide is a skeleton.** The structure, the checkpoints, and the failure
branches are written. The specific values, photographs, and anything that
depends on a physical board are marked and missing, because the board does not
exist yet. Do not attempt to build from this expecting every number to be there.

## Before you start

Read [Safety and rules](/safety) first, particularly the lithium cell section.
The cell is the only part of this project whose failure mode is fire.

Have the [bill of materials](/bom) open. Check every part against it before you
heat the iron, including the ones you already own, because a substitution you
made months ago is not a substitution you will remember today.

Work somewhere you can leave things out. Putting a half-finished board in a
drawer loses more than it saves.

TODO(verify): say how long this build actually takes, and whether it is
realistically one sitting or two, once `build_time_estimate` in
`data/tiers.yaml` is filled from timing people who have soldered before. The
brief's "an evening" is a target, not a measurement.

## Stage 0: Sort and inspect

1. Lay every part out and identify it against the bill of materials.
2. Check the battery connector polarity against the board silkscreen.
   **Do not skip this.** Lithium cells ship with both polarities on the same
   connector, and reversing one can destroy the board instantly.
3. Inspect the cell for swelling, dents, and damaged wire insulation. Set it
   aside, in its bag, with the connector taped. It does not come out again until
   Stage 5.

> **Checkpoint 0.** Every part on the list is present and identified, and you
> know which pin of your cell's connector is positive. If the polarity does not
> match the silkscreen, stop and read
> [it runs on USB but dies immediately on battery](/troubleshooting#short-battery)
> before going further.

TODO(photo): the full parts layout for a Track build on the Modules path, top
down, every part labelled, on a plain background. This is the photo people
screenshot to check their order arrived complete.

## The path fork

The rest of this guide splits once, here, and rejoins at Stage 4.

- **Modules path**: Stages 1M to 3M. Breakout boards wired to a carrier.
- **Board path**: Stages 1B to 3B. The custom oApogee PCB.

Everything from Stage 4 onward is identical. Firmware, mounting, calibration,
testing and flying do not care which way you built it.

If you are not sure, build Modules. The board is not fabricated yet.

---

## Modules path

### Stage 1M: The microcontroller carrier

1. Fit the microcontroller module to the carrier board or protoboard.
2. Solder the power and ground connections first, and nothing else yet.
3. Inspect every joint under magnification before applying power.

TODO(confirm-on-hardware): the specific module has not been selected. This stage
cannot be written concretely until it is. See the verify note on `mcu_module` in
the bill of materials for the selection criteria.

> **Checkpoint 1M.** With the multimeter in continuity mode and no power
> connected, there is no continuity between 3V3 and ground. If there is, you have
> a bridge, and finding it now costs a minute rather than a board.

4. Connect USB. The module should enumerate.

> **Checkpoint 1M-b.** The board appears to your computer. Holding the boot
> button while plugging in should present it as a USB drive. Releasing and
> replugging normally should present it as a serial device.
>
> Nothing appears: [it powers on but does not appear as a USB drive](/troubleshooting#not-a-drive).
> Nothing at all happens: [nothing happens when I plug it in](/troubleshooting#no-power).
> Try a different cable before anything else. Charge-only USB-C cables look
> identical to data cables and are the most common cause of both symptoms.

### Stage 2M: Sensors onto their buses

The sensors do not share one bus. The barometer sits on I2C, the IMU and the
high-g accelerometer share an SPI bus with a chip select each, and the GNSS
receiver sits on a UART. Fit the barometer alone first and confirm it, so one
part is proven before a second bus exists to complicate the picture.

1. Fit the barometer breakout.
2. Wire power, ground, SDA and SCL.
3. **Check the I2C pull-up resistors.** The barometer is the only part on this
   bus, so there should be exactly one pull-up pair on SDA and SCL. Count any
   the carrier or the microcontroller module already provides, not just the
   pair the breakout brings. Most breakouts have a jumper or a solder bridge to
   remove theirs.

TODO(confirm-on-hardware): this guide does not rank the Modules-path failure
modes by how often they happen, because ranking them needs reports from builds
that have actually happened.

> **Checkpoint 2M.** The serial console reports the barometer present and prints
> a pressure. Check it against the station pressure your local weather service
> publishes, not against a fixed band: standard sea level is 101325 Pa and the
> reading falls as elevation rises, so a correct sensor at a mile-high field
> reads far below any sea level figure. What tells you the part works is a value
> that is stable, plausible for where you are, and that rises slightly when you
> carry the board downstairs. A reading of zero, or a part that never appears at
> all, means [the barometer never appears on the bus](/troubleshooting#baro-missing).

4. Fit the IMU on the SPI bus: SCK, MOSI, MISO, and a chip select of its own.
   Confirm it before continuing.
5. Fit the high-g accelerometer if you are building one, on the same SPI bus,
   with a second chip select that is not shared with anything. Confirm it.
6. Fit the GNSS receiver if you are building Track, on a UART, with TX and RX
   crossed. Confirm it.

> **Checkpoint 2M-b.** Every sensor you fitted reports present, and the values
> move sensibly when you move the board: tilting changes the accelerometer axes,
> rotating changes the gyroscope, and lifting it changes the pressure very
> slightly. Intermittent dropouts as you add parts mean
> [sensors drop out intermittently](/troubleshooting#intermittent-sensor).

### Stage 3M: Radio, recovery aids, and power

1. Fit the radio module if you are building Link or Track.
2. **Attach the antenna before you ever transmit.** Transmitting into a
   disconnected antenna is bad for the radio.
3. On Track, fit the GNSS antenna too, and give it a view of the sky. A
   receiver with no antenna does not report a poor position, it reports none at
   all, and the symptom on the bench looks the same as a receiver that is
   simply still searching.
4. Fit the buzzer and the status LED.
5. Fit the arming switch. The centre pin goes to the arming GPIO and one outer
   pin goes to ground. The third pin is deliberately left unconnected.
6. Fit the battery connector, checking polarity one more time.

> **Checkpoint 3M.** The buzzer sounds and the LED lights on command from the
> console. The console reports armed and disarmed as you move the switch, and
> the reported state matches the position you can see. The radio reports
> present. You have not transmitted yet.

---

## Board path

TODO(confirm-on-hardware): this entire path depends on a fabricated PCB. Nothing
below can be written concretely until boards exist, and none of it has been
performed.

### Stage 1B: Power section

1. Solder the regulator, its passives, and the USB connector.
2. Solder the charge controller and its programming resistor.
3. Solder the core regulator inductor, L1. The microcontroller runs its core
   from an internal switching regulator and this is the one part of that
   regulator that lives outside the chip. Without it the core rail never comes
   up, which looks exactly like a dead microcontroller.

> **Checkpoint 1B.** With no power applied, no continuity between 3V3 and
> ground. With USB applied and nothing else populated, 3V3 measures within
> tolerance at the regulator output.

TODO(verify): state the acceptable voltage range at this checkpoint, from the
chosen regulator's datasheet.

### Stage 2B: Microcontroller and flash

The microcontroller is a 60 pin QFN on a 0.4 mm pitch with a thermal pad on its
underside, and the pad has to be soldered: it is the part's only ground
connection. That means hot air, a hotplate or a reflow oven, and a stencil for
the paste. An iron cannot reach under the part. If that is not equipment you
have, the Modules path exists for exactly this reason, and having the board
assembled by the fab is the other answer.

1. Solder the microcontroller.
2. Solder the QSPI flash.
3. Solder the crystal, its two load capacitors, and the damping resistor next
   to it. Keep these joints tidy and keep the parts flat: this is the circuit
   the USB connection depends on, and a board with a crystal that does not
   start looks exactly like a board that is dead.

> **Checkpoint 2B.** Hold SW2, tap SW3, release SW2, and the board appears to
> your computer as a USB drive. Copying a known-good test firmware onto it
> causes the status LED to light.
>
> There is no dedicated bootloader pin on this microcontroller. Holding the
> flash chip select low as the chip leaves reset is what selects USB boot, which
> is what those two buttons do. A board with blank flash will also appear as a
> drive on its own, because the bootrom falls through to USB when it finds
> nothing to run, so the first flash works even if a button is unsoldered. The
> buttons are what let you do it a second time.

### Stage 3B: Sensors, radio, and connectors

1. Solder the barometer, the IMU, and the high-g accelerometer if fitting one.
2. Solder the radio and the GNSS receiver if fitting them, and the coaxial
   socket that goes with each. They are the same part in two places: J3 feeds
   the radio antenna, J5 feeds the GNSS antenna.
3. Solder the battery connector, the buzzer, the LED, and the arming switch.
4. Solder the USB connector last. Its legs pass through the board and it sits
   over other work, so fitting it early makes everything under it harder to
   reach and harder to inspect.

> **Checkpoint 3B.** Every populated part reports present over the serial
> console, and the sensor values move sensibly when you move the board. The
> console reports armed and disarmed as you move the switch, and the reported
> state matches the position you can see.

TODO(photo): a completed board, top and bottom, at high enough resolution to
check joint quality against.

---

## Stage 4: First real firmware

Both paths rejoin here.

1. Follow [Firmware and flashing](/firmware) to load the current release.
2. Run the self-test from the serial console.

> **Checkpoint 4.** Self-test passes for every part you fitted, and reports
> absent for every part you did not. A part you fitted that reports absent is a
> soldering problem, not a firmware problem. A part you did not fit reporting
> present means the firmware is misconfigured for your tier.

3. Run the pad calibration procedure.

> **Checkpoint 4-b.** Reported altitude sits near zero and stays there, drifting
> only slowly. Large or fast drift at this point means the pressure reference did
> not settle. A large negative starting value means it was taken somewhere else:
> see [my altitude reads negative](/troubleshooting#altitude-negative).

## Stage 5: Battery

1. Connect the cell, having checked the polarity for the third time.
2. Confirm the board runs from the cell with USB disconnected.
3. Confirm charging works with USB connected.

> **Checkpoint 5.** It runs on the cell alone and charges when plugged in. If it
> runs on USB and dies on the cell, stop and read
> [it runs on USB but dies immediately on battery](/troubleshooting#short-battery).

TODO(confirm-on-hardware): document the LED behaviour for charging, charge
complete, and charge fault, once that behaviour is implemented.

## Stage 6: Into the enclosure

Follow [Mounting](/mounting) for the sled or the pod, whichever form factor you
are using. That page also covers the static ports, which are not optional and
are the most commonly botched part of the whole build.

1. Print the enclosure for your form factor and airframe diameter.
2. Secure the board so it cannot move.
3. Secure the cell so it cannot move, and route the wires so the enclosure
   closing cannot pinch them.
4. Drill and deburr the static ports.

> **Checkpoint 6.** Shake the closed assembly hard and listen. Nothing rattles,
> nothing buzzes, nothing shifts. Anything you can hear moving in your hand will
> move much harder under boost. Open it and confirm the cell is still where you
> put it.

## Stage 7: Ground testing

Do all four tests on the [safety page](/safety#ground-testing), in order, before
this goes anywhere near a rocket: the bench dry run, the shake test, the drop
test, and the full arm-to-landing rehearsal. A payload that is going to fail
should fail on your bench, where it costs an evening.

> **Checkpoint 7.** A complete log file, on the flash, that exports to CSV and
> opens. If you can read a bench run end to end, you can read a flight.

## Stage 8: The rocket

1. Re-simulate your rocket in OpenRocket with the payload mass and position
   included. This is not optional and it is the step with a consequence for
   people other than you.
2. Fit the payload.
3. Confirm the rocket still slides freely on the rail, with the pod fitted. An
   external pod is the most common thing to catch on a rail button.

> **Checkpoint 8.** You have re-simulated with the payload's measured mass at
> the position you actually mounted it, the margin has not gone backwards, and
> the rocket moves freely on the rail with the pod fitted.

TODO(verify): this checkpoint asks whether the margin moved, not whether it
clears a threshold, because this site does not yet publish a threshold. The
[safety page](/safety#stability-is-a-safety-issue) says why: the caliber margin
to aim for needs quoting from NAR or Tripoli guidance rather than asserting,
and that has not been done. Until it is, use the margin your rocket flew well
at as the reference and treat a large move as a reason to stop.

Then work through the [preflight checklist](/preflight) on the day.

## Ground station

If you built Link or Track, you also need a receiver. That is a separate build:
see [Ground station](/ground-station).

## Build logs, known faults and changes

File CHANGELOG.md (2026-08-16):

# Changelog

Notable changes to oApogee, hardware, firmware, and documentation together.

Errata are safety information. When hardware and firmware ship, a change to a
detection threshold or a known defect in a board revision appears here, because
somebody flying the previous version needs a way to find that out.

Dates are ISO. Versions follow the repository's `VERSION` file.

## Unreleased

### Added

- **The board.** The circuit source carries footprints and placement for 42
  parts, and the layout routes with nothing unrouted. Two pinouts are
  transcribed from the manufacturer's own datasheet rather than assumed: the
  RP2350's sixty pins, and the SX1262's twenty-five.

  The fabrication package is gated behind a verification pass that refuses to
  write it while any blocker is open, and there are open blockers, so it is not
  published. That gate is the feature. It has already stopped one board whose
  radio had no reference oscillator from being orderable.
- **Firmware.** Sixteen core modules in freestanding C11, host-testable with
  nothing but cmake and a compiler, thirteen test binaries. The passive boundary
  is enforced by a check over the sources rather than asserted in a comment, and
  every flight threshold starts unset so the payload refuses to arm on a guess.
- **A second implementation of the packet format**, in TypeScript, written from
  the specification rather than from the C. `make crossimpl` builds fifteen
  canonical packets with both and compares them byte for byte, which is evidence
  a conformance test cannot produce.
- **A ground station in the browser.** WebSerial receiver with a simulated
  flight, and a live packet decoder on the specification page.
- **The printed parts**, as OpenSCAD source rather than only STLs: an internal
  sled and a two-piece external pod, generated from twenty-eight dimensions that
  each carry where they came from.
- Two format specifications, published so third parties can write their own
  tools. `docs/spec/telemetry-packet.md` fixes the downlink wire format at
  version 1; `docs/spec/log-format.md` fixes the onboard log at version 1. Both
  carry a reference implementation and conformance rules.
- Structured source for the bill of materials, tiers, glossary, flight state
  machine, preflight checklist, troubleshooting index, system diagram, mechanical
  dimensions, suppliers, and the flight log submission format.
- The system block diagram, generated from `data/system.yaml` rather than drawn,
  with a build check that fails when the committed SVG stops matching the data.
- Content pages: start here, build guide, firmware and flashing, mounting,
  ground station, reading your data, safety and rules, reference, FAQ, about and
  license.
- **Checks, because a rule nobody enforces is a rule that gets broken.** Prose
  style; every physical quantity in published prose having a stated source; data
  cross-references; internal links, now including the ones written in the site's
  own source; no page scrolling sideways on a phone; every drawing actually
  panning and zooming with the drawing in frame; the firmware's passive boundary
  and its ban on hardcoded thresholds; the two packet implementations agreeing;
  the printed parts matching their dimensions; the board's own design rules; and
  supplier links resolving.

### Fixed

- **The board had no crystal.** XIN and XOUT were declared on the
  microcontroller and connected to nothing. The RP2350 runs without one, so
  nothing complained, and the board would have been unflashable: USB needs an
  accurate reference and USB is its only connector. Now Raspberry Pi's own
  circuit, their crystal, their capacitor values, their damping resistor.
- **The GNSS receiver had no antenna.** RF_IN was declared and connected to
  nothing, which is a Track tier that cannot produce a position, the one thing
  that tier is for. It now has a coaxial socket of its own.
- **A footprint that did not exist produced a part with no pads.** Asking
  tscircuit for a footprint it does not have is not an error that stops
  anything: it logs a message, exits zero, and builds the component with no
  copper, so the part is on the schematic and its net silently has none. Both
  coaxial sockets now use a land pattern defined in the source.
- Three new checks, one per defect above, because each of them built cleanly,
  routed cleanly, exported a clean fabrication package and passed every check
  in this repository. A named pin must now be connected or listed with the
  reason it is not; a rejected component property is a blocker; and the count
  of copper pairs too close together for the cheaper fabricator is ratcheted
  rather than only printed, after it doubled in one commit with nothing to say
  so.
- The ground station page said every packet carries a device identifier. The
  header has no identifier field. It now says so, says what to do instead, and
  the question of whether one belongs there is in `docs/open-questions.md`.
- Troubleshooting had path gating in the data that the page never rendered, so
  Modules builders were sent looking for parts that only exist on the custom
  board.

### Decided

- **No microSD socket.** Card sockets unseat under boost, and the failure mode
  is the worst available: the flight proceeds normally and the data is gone.
  Storage is soldered-down QSPI flash with LittleFS.
- **Passive instrumentation only.** No ejection charge control, no deployment
  control, no igniters, no pyrotechnics, at any tier, ever. The boundary keeps
  the worst outcome of any bug in this project a disappointing graph.
- **Raw and derived values are both logged.** Twelve of thirty-six bytes per
  record, spent so the payload's own work can be audited and so old flights can
  be reprocessed with a better filter.
- **No encryption on the downlink**, so the link stays legal to transmit under
  amateur radio rules. Compact binary is efficiency; scrambling would be
  obfuscation.
- **Two build paths.** Modules, on breakout boards, buildable before a PCB
  exists. Board, the custom PCB. The tier owns the capability content and the
  path owns only the assembly content.
- **The high-g accelerometer is optional at every tier, including Solo.**
  Whether an IMU saturates depends on the motor, not on whether the board has a
  radio, and tying the part to Link left the cheapest build most likely to record
  a boost phase that is silently wrong.
- **The arming switch is mechanical.** The case for a magnetic one was a sealed
  enclosure, and the pod is deliberately vented, so sealing was never on offer.
  What is left is trading a state you can see for one a stray magnet can change.
- **The sled is sized for BT-55, and the 24 mm case is pod only.** A 22 mm board
  in a BT-50 bore leaves 0.6 mm of rail, which a slicer will emit and a landing
  will break.
- **WebSerial for the ground station**, with the browser requirement stated
  prominently and a documented terminal fallback. It excludes iOS and the
  alternatives are worse; the wire format is published so somebody else can build
  an iOS client without asking.
- **A complementary filter for v1.** Tuning a Kalman filter would mean inventing
  covariances for sensors that have never flown.
- **`SIM` stays a flag, not a packet type**, with the conformance rule raised
  from should to must: a parallel type for everything simulable would double the
  type space to encode a property orthogonal to the packet's contents.
- **Log block checksums go in the manifest** every flight already writes, which
  keeps the flat-array property that makes the format one line to load.
- **The watchdog is enabled in flight**, with the peak altitude committed as it
  updates. A hung payload cannot be found; a reset keeps the beacon alive, and
  the cost of the reset is the part that is fixable.
- **Licensing.** CERN-OHL-S 2.0 for hardware, Apache 2.0 for firmware and
  software, CC BY-SA 4.0 for documentation. Reciprocal on the board because the
  plausible bad outcome is a closed volume clone and `-S` at least requires that
  improvements come back; permissive on the firmware because that is the part
  worth having other people embed everywhere, with Apache over MIT for the
  express patent grant. The documentation gets share-alike, accepting that a
  competitor may reproduce the build guide commercially with attribution.
- **Trademark policy.** The design is open, the name is not. Licences do not
  stop a clone shipping under this name; a trademark does. Not registered yet:
  registration buys enforceability against a problem that does not exist while
  nothing is being sold.

Every one of these is argued out, with the case against, in
[docs/open-questions.md](https://github.com/Xaxis/oapogee.space/blob/main/docs/open-questions.md).

### Status

**Nothing physical exists.** No board has been fabricated, assembled, weighed,
priced, or flown. Every cost, mass, range and endurance figure on the site is
absent rather than estimated, and each gap records what evidence would close it.

The PCB is a real step past a paper design and is not the same as a board that
works. Its fabrication files are not published, because the check that gates
them refuses while anything is open, and two things are:

Seven parts have footprint pads the source never named, so those pads sit on the
board connected to nothing. On an integrated circuit an unnamed pad is a supply
rail or a crystal terminal, which is how this board reached a clean export with
a microcontroller that had no crystal and a GNSS receiver that had no antenna.
Both are fixed; the remaining seven pinouts are being transcribed one datasheet
at a time.

The radio's RF front end is not designed. Between the transceiver's transmit
output, its receive inputs and one antenna, the reference design puts a switch
and about fourteen matching components whose values Semtech does not print in
the datasheet. That argument is in `docs/open-questions.md` with the three ways
to close it.

The [schematic page](https://oapogee.space/reference/schematic) says all of this
on every build, generated from the check rather than written by hand.

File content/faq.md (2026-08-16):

---
title: FAQ
description: Questions people actually ask about oApogee, including the ones with unsatisfying answers.
tier: all
difficulty: beginner
time_estimate: null
updated: 2026-08-11
status: draft
---

# FAQ

Real questions only. Anything asked twice in the wild gets added. Nothing here
is invented as a way of writing marketing copy in question form.

Because the project is new, this page is short, and most of what is here is
questions asked during the design rather than by builders. It will get longer
and more useful as people build things.

## Can I buy one?

Not yet. Kits are intended eventually, and nothing has been fabricated, so there
is nothing to sell. You can order the bare PCB yourself from the published
fabrication files, with the caveat on the schematic page: the pin numbering of
most packages has not been checked against a datasheet.

## Can it deploy my parachute?

No, and it never will.

oApogee is a passive instrumentation payload. It does not fire ejection charges,
control deployment, ignite motors, or command any pyrotechnic device. Your
recovery system is the motor's ejection charge and delay grain, exactly as it
was before you fitted a payload.

This is a design boundary rather than a missing feature. Deployment control
carries a completely different set of failure consequences and belongs to
certified high power rocketry.

## Why is there no price on the bill of materials?

Because nothing has been bought, so there is no honest number to put there.

This site does not publish figures it has not measured or sourced. The targets in
the project brief are under $60 for the full build and under $30 for the entry
build, but a target is not a measurement, and printing one as though it were is
how a site becomes untrustworthy.

## Do I need to know how to program?

No. The microcontroller is flashed by dragging a file onto what appears as a USB
drive. There is no toolchain to install.

You do need to have soldered before, and to be able to use a multimeter for
continuity and voltage.

## Do I need a radio licence?

Not for the default configuration. oApogee Link and Track use the 902 to 928 MHz
band in the US under FCC Part 15, which requires no licence and no callsign.

oApogee Solo has no transmitter at all, which is one of the reasons it exists.

If you hold an amateur licence there is a separate path with more transmit power
available, covered on the [safety page](/safety). Those two regimes are
different and the site never mixes them.

## Can I fly it outside the US?

The band changes and so do the rules. A 902 to 928 MHz module is not legal to
operate in most of Europe, where the equivalent short range band is 863 to
870 MHz, and that is a different radio module rather than a firmware setting.

The EU and UK rules are not yet documented properly on this site, including
whether airborne use is permitted, which several national administrations
restrict. That is marked as unfinished rather than guessed at. See the
[safety page](/safety).

## Will it fit my rocket?

The external pod straps to the outside of any body tube and requires no
modification to the airframe, which is what makes it work on a rocket you
already own. That is the answer for a small rocket.

The internal sled is cut for a BT-55 payload bay by default, and it needs a
rocket that has a payload bay. It is not offered for a BT-50, and that stopped
being a judgement call once the board grew: the board is now wider than a BT-50
bore, so it does not go in at all, with or without a sled around it. Both parts
are parametric: measure your own tube and re-render.

The pod costs you drag and moves your centre of gravity, so
[re-simulate](/mounting) before flying. That is not a formality.

## What is the highest it can go?

TODO(verify): two separate ceilings, and readers will conflate them. The
barometer has a usable pressure range that corresponds to some altitude, and the
radio has a practical range that is usually the lower limit in practice. Both
need stating with their conditions.

The design target is low power flying, A through E motors, with headroom so that
F and G are not blocked later.

## Why not a microSD card?

Because card sockets unseat under boost.

A microSD card is held in by a friction detent, and the acceleration on even a
modest motor is enough to move it. In DIY flight computers this is the single
most common in-flight failure, and its failure mode is the worst available: the
flight proceeds normally and the data is simply gone.

The flash on oApogee is soldered down and cannot unseat. The cost is that you
offload over USB instead of moving a card, which is a mild inconvenience on the
ground in exchange for removing a failure mode in the air.

## Why does my altitude read slightly negative after landing?

That is usually correct rather than a fault.

Altitude is measured against a pressure reference taken on the pad. If
atmospheric pressure rose during the flight, or the rocket landed lower than the
pad, the reading goes negative. oApogee does not clamp it at zero, because
clamping would hide a real measurement.

See [my altitude reads negative](/troubleshooting#altitude-negative) for the
cases where it does indicate a problem.

## What does the `o` stand for?

Open. That is the whole story, and it is told once, on the [about page](/about).

## How do you pronounce it?

"oh-APP-uh-jee."

## Is this related to Apogee Components?

No. oApogee is not affiliated with Apogee Components, who are an unrelated and
much older retailer in this hobby. The name is never shortened to "Apogee" for
exactly that reason.

## Can I help?

Yes, and the most useful help right now is telling us where the site is wrong.

The safety and regulatory pages especially. They are written carefully and have
not been reviewed by anyone with formal expertise in the rules they describe.

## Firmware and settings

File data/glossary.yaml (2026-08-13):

# oApogee glossary
#
# Canonical definitions. Prose pages give a one-clause gloss on first use and
# link here for the full definition. Terms are added as pages are written, so
# this file grows; it does not get rewritten.
#
# Fields:
#   term        the display form, sentence case unless it is a proper noun
#   id          slug, used as the anchor and the link target
#   aliases     other spellings that should resolve to this entry
#   short       one clause, for a hover or an inline gloss
#   long        the full definition, for the glossary page
#   see_also    other term ids
#   source      primary source URL where the term is legally or formally defined

schema_version: 1
updated: 2026-08-11
status: draft

terms:
  - id: apogee
    term: apogee
    short: the highest point of the flight
    long: >
      The highest point a rocket reaches, and the instant at which its vertical
      velocity passes through zero. It is the single number most fliers want,
      and it is what the project is named after. Note that apogee and the moment
      of parachute deployment are not the same event: a motor's delay grain is
      chosen to fire the ejection charge near apogee, and how near is a measure
      of how well the flight was planned.
    see_also: [delay-grain, coast]

  - id: oapogee
    term: oApogee
    short: this project, an open source rocket telemetry payload
    long: >
      An open source telemetry payload for model rockets, and the documentation
      that teaches you to build one. Written oApogee, one word, lowercase o,
      capital A. Never shortened to "Apogee", which in this hobby means Apogee
      Components, an unrelated retailer.
    aliases: [oapogee]

  - id: telemetry
    term: telemetry
    short: measurements taken on the vehicle and sent to the ground
    long: >
      Measurement at a distance. On oApogee it means the flight data recorded on
      the payload, and on Link and Track, the live stream of that data sent down
      to a ground station while the rocket is still flying.

  - id: payload
    term: payload
    short: anything the rocket carries that is not part of flying it
    long: >
      Whatever the rocket carries beyond what it needs to fly. On a model rocket
      this is usually an altimeter, a camera, or an egg. oApogee is a payload,
      specifically a passive instrumentation payload, meaning it observes and
      records but does not act on the rocket.
    see_also: [passive-payload]

  - id: passive-payload
    term: passive instrumentation payload
    short: a payload that only measures, and never commands anything
    long: >
      A payload that records and transmits but never actuates. oApogee does not
      fire ejection charges, control deployment, ignite motors, or command any
      pyrotechnic device. This is a scope boundary, not a limitation to be
      removed later. A payload that can fire a charge has a completely different
      failure consequence profile and belongs to certified high power rocketry.
    see_also: [ejection-charge, high-power-rocketry]

  - id: static-port
    term: static port
    short: a vent hole that lets the barometer see outside air pressure
    long: >
      A hole in the airframe, positioned so the pressure sensor inside reads
      ambient static pressure rather than the pressure of a sealed volume or the
      dynamic pressure of moving air. A barometric altimeter inside a sealed tube
      measures the tube, not the sky, and produces confident nonsense. Sizing,
      count, placement relative to the sensor, and deburring all matter.
    see_also: [barometric-altitude]

  - id: barometric-altitude
    term: barometric altitude
    short: altitude inferred from air pressure
    long: >
      Altitude calculated from the drop in atmospheric pressure with height,
      relative to a pressure reference taken on the ground before launch. It is
      the standard method for model rocket altimeters because it needs one small
      cheap sensor. Its weaknesses: it is noisy, it is disturbed by airflow
      around the airframe, and because the ground reference is taken once, a
      weather system moving through during a long pad wait shifts the zero.
    see_also: [static-port, pad-calibration, sensor-fusion]

  - id: pad-calibration
    term: pad calibration
    short: averaging ground pressure before launch to set the altitude zero
    long: >
      The procedure of sampling atmospheric pressure while the rocket sits on the
      pad and averaging it over a settling window, to establish the zero
      reference that every later altitude is measured against. Without it, the
      altimeter reports height above sea level rather than height above the
      launch site.
    see_also: [barometric-altitude]
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

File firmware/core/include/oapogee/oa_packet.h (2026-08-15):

/*
 * oApogee downlink packet builders.
 *
 * One build function per packet type, writing a complete packet into a buffer
 * the caller owns. There is no allocation, no packet object, and no partial
 * state between calls: a packet is a pure function of a header and a body.
 *
 * The enumeration, the length constants, the body structs and the build
 * function declarations below are all expanded from
 * oapogee/oa_packet_fields.def, which is expanded again by the encoder and again
 * by the conformance test that dumps the layout. A field that moves moves in one
 * place, and everything that disagreed with it fails to build or fails a test.
 *
 * Source of truth: docs/spec/telemetry-packet.md, spec_version 1.
 *
 * THERE IS NO DECODER HERE, AND NO PARSER. The payload builds packets and
 * transmits them. It never interprets a packet it did not build, because there
 * is nothing on the air it should obey. See firmware/SAFETY.md.
 *
 * Nothing in this file has run on hardware, and no byte of this format has been
 * observed on a radio.
 */

#ifndef OAPOGEE_OA_PACKET_H
#define OAPOGEE_OA_PACKET_H

#include "oa_states.h"
#include "oapogee/oa_crc.h"
#include "oapogee/oa_flags.h"
#include "oapogee/oa_types.h"

#ifdef __cplusplus
extern "C" {
#endif

/* ---------------------------------------------------------------------------
 * Format constants.
 *
 * These are the format, not tuning. They belong in code.
 * ------------------------------------------------------------------------ */

/* High nibble of byte 0. A receiver must reject a version it does not know
 * rather than attempting to decode it, because field offsets are not guaranteed
 * stable across versions. */
#define OA_PROTOCOL_VERSION (1u)

#define OA_PACKET_HEADER_BYTES (8u)
#define OA_PACKET_CRC_BYTES    (OA_CRC16_BYTES)

/* The longest packet in version 1 is BEACON at 22 bytes. A caller that sizes a
 * buffer with this can build any packet type into it. The _Static_asserts below
 * check it against the table rather than trusting this line. */
#define OA_PACKET_MAX_BYTES (22u)

/* pad_pressure_pa_off in STATUS is offset so the useful range fills 16 bits:
 * the transmitted value is pressure_pa - 50000, covering 50000 to 115535 Pa in
 * 1 Pa steps. Without the offset a u16 of whole pascals would stop at 65535 Pa,
 * below the pressure at any launch site anyone flies from. */
#define OA_PAD_PRESSURE_OFFSET_PA (50000)
#define OA_PAD_PRESSURE_MIN_PA    (50000)
#define OA_PAD_PRESSURE_MAX_PA    (115535)

/* Latitude and longitude carry this when there is no fix, in both BEACON and
 * POSITION. Zero is a real coordinate, which is why it cannot be the sentinel.
 * GNSS_FIX in the header is authoritative and a receiver must check it. */
#define OA_LATLON_NO_FIX (INT32_MIN)

/* ---------------------------------------------------------------------------
 * Packet types, and their lengths, from the table.
 * ------------------------------------------------------------------------ */

/* 0x0 and 0x6 to 0xF are reserved. There are no enumerators for them: a reserved
 * type is not something the payload can be asked to send. */
typedef enum {
#define OA_PKT_TYPE_BEGIN(SYM, sym, code, body_len, total_len) OA_PKT_##SYM = (code),
#include "oapogee/oa_packet_fields.def"
    OA_PKT_TYPE_COUNT = 5
} oa_packet_type_t;

/* Per-type lengths as enumerators, because the preprocessor cannot emit a
 * #define from a macro expansion and a hand-written parallel list of lengths is
 * exactly the drift this table exists to prevent. */
enum {
#define OA_PKT_TYPE_BEGIN(SYM, sym, code, body_len, total_len) \
    OA_PKT_##SYM##_BODY_BYTES = (body_len),                    \
    OA_PKT_##SYM##_TOTAL_BYTES = (total_len),
#include "oapogee/oa_packet_fields.def"
    OA_PKT_LENGTHS_END = 0
};

/* header + body + CRC must equal the stated total for every type, and no type
 * may exceed the buffer size callers are told to allocate. The spec states body
 * and total separately, so the arithmetic between them is checkable, and this is
 * where it gets checked: at compile time, on every build, for free. */
#define OA_PKT_TYPE_BEGIN(SYM, sym, code, body_len, total_len)                      \
    _Static_assert((body_len) + (int)OA_PACKET_HEADER_BYTES + (int)OA_PACKET_CRC_BYTES \
                       == (total_len),                                              \
                   "packet " #SYM ": header + body + CRC does not equal the stated total"); \
    _Static_assert((total_len) <= (int)OA_PACKET_MAX_BYTES,                          \
                   "packet " #SYM " is longer than OA_PACKET_MAX_BYTES");
#include "oapogee/oa_packet_fields.def"

/* ---------------------------------------------------------------------------
 * The header a caller supplies.
 *
 * Byte 0 is not in this struct. It is the version nibble and the type nibble,
 * and the builder derives it from the function that was called. A caller that
 * could set it could transmit a FLIGHT body under a STATUS type byte, and every
 * receiver would decode the result as a valid packet.
 *
 * t_ms is milliseconds since the transition into ARMED. The builders transmit 0
 * when `state` is OA_STATE_PAD_IDLE regardless of what this field holds, because
 * the spec requires it and because the payload's uptime counter is a firmware
 * implementation detail that is never on the air.
 * ------------------------------------------------------------------------ */

typedef struct {
    uint8_t  flags; /* OA_FLAG_* bits. Bit 7 is cleared by the builder. */
    uint8_t  seq;   /* Increments per transmitted packet, wraps at 255. */
    uint8_t  state; /* oa_state_t value, or a reserved value passed through. */
    uint32_t t_ms;  /* Milliseconds since arming. Sent as 0 in PAD_IDLE. */
} oa_packet_header_t;

/* ---------------------------------------------------------------------------
 * Body structs, one per packet type, generated from the table.
 *
 * These are host-order decoded values, not overlays. The packet is written field
 * by field in little-endian order, never by copying one of these structs, because
 * a struct overlay depends on packing attributes and on the host's endianness and
 * this format is meant to be implementable anywhere.
 * ------------------------------------------------------------------------ */

#define OA_PKT_TYPE_BEGIN(SYM, sym, code, body_len, total_len) typedef struct {
#define OA_PKT_BODY_FIELD(name, wire, offset) oa_##wire##_t name;
#define OA_PKT_BODY_FIELD_GNSS(name, wire, offset, absent) oa_##wire##_t name;
#define OA_PKT_TYPE_END(SYM, sym) \
    }                             \
    oa_##sym##_body_t;
#include "oapogee/oa_packet_fields.def"
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

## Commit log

2026-08-11 Scaffold oApogee: content pipeline, BOM data, safety page, site
    Sets up the repository around the constraint that makes this project worth
    existing: the documentation is the product, so it never publishes a number it
    has not measured or sourced.
    That rule is mechanical, not aspirational. Verification markers are written
    inline where they are useful to an editor, aggregated into TODO-VERIFY.md by
    tools/collect-todos.mjs, and CI fails when that index goes stale, so the site
    cannot quietly understate how much of itself is unmeasured. tools/check-data.mjs
    enforces the contract from both sides: a null price must carry a marker saying
    what evidence would close it, and no page may claim `verified`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
    [glossary.yaml]
2026-08-11 Generate the system schematic from data, drop the public page map
    The block diagram is rendered by tools/gen-schematic.mjs from data/system.yaml,
    whose nodes name part ids in data/bom.yaml. check-data fails when a reference
    stops resolving and CI fails when the committed SVG no longer matches the data,
    so the diagram cannot quietly stop describing the hardware. A diagram maintained
    by hand disagrees with the board within a month, and nobody notices until a
    builder follows it.
    The tier ticks on each block are the upgrade promise drawn rather than asserted:
    Solo is visibly the same board with two footprints left empty.
    Adds the 3V3 regulator, which the parts list was missing. A single cell c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
2026-08-12 Write the specs, the remaining pages, and the routes for all of them
    Two format specifications, written early because the data format is where the
    firmware and the site have to agree and getting it wrong later is expensive.
    docs/spec/telemetry-packet.md fixes the downlink wire format: 8-byte header,
    five packet types, CRC-16/CCITT-FALSE, and conformance rules a receiver must
    follow. Apogee gets its own preempting packet type because it happens once, at
    the greatest distance from the receiver, immediately before the event most
    likely to damage the payload. There is no packet that can command the vehicle
    and no encryption, so the link stays legal to transmit under Part 97.
    docs/spec/log-form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
2026-08-12 Decide the licensing, and stop next dev clobbering production builds
    Three licences, because this repository holds three different kinds of thing and
    treating them alike would be wrong in both directions.
    CERN-OHL-S 2.0 for hardware. The plausible bad outcome for a project like this
    is a manufacturer producing the board at volume as a closed product. Reciprocity
    does not prevent that and is not meant to, but it requires that improvements
    come back. The cost, accepted: some vendors avoid reciprocal licences, and
    permissive would reach more hands faster.
    Apache 2.0 for firmware and software. This is the part most likely to end up
    embedded in somebody else's project, and that should be easy.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
2026-08-12 Add the circuit as tscircuit source, rendered to schematic, netlist and KiCad
    hardware/oapogee.tsx defines the payload as code. make hw renders four
    artifacts from it: the netlist as text, the schematic as SVG, a KiCad schematic,
    and circuit JSON. make check-hw fails when the committed drawing stops matching
    the source, so the schematic cannot drift from the design the way a hand-drawn
    one does.
    The KiCad export is what makes the openness promise checkable. The About page
    says this project publishes the KiCad project rather than a PDF of a schematic,
    and now it does.
    The critical framing, repeated in the file header, in hardware/README.md, and
    wherever the site shows this: it is a netlist,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
    [oapogee.kicad_sch]
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2026-08-12 Fix CI: pin the node version CI actually needs
    CI had never passed. .nvmrc pinned 22.11.0, and a transitive dependency
    requires ^22.13.0 || >=24, so yarn install --frozen-lockfile failed on every run
    while the same install succeeded locally on 24.3.0.
    The Makefile header claims that what CI runs and what a contributor runs locally
    cannot diverge. That claim was false in the one place it mattered most, and the
    divergence is exactly what hid the failure: every local check was green.
    .nvmrc now matches the local toolchain, and engines states the real floor rather
    than an optimistic >=22.
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2026-08-12 Fix 37 audited defects, wire the board's power, and make zoom crisp
    A four-way audit with adversarial verification found 37 confirmed defects, seven
    of them blockers. The verifier's job was to refute each finding, so what
    survived is what could be proven from the files.
    Specs. The STATUS pressure field's stated range did not follow from its own
    encoding formula and matched no consistent reading of it, so two implementers
    would have clamped and raised BARO_FAULT at different pressures. It is now
    whole pascals offset by 50000, which covers 50000 to 115535 Pa in exactly 65536
    codes, makes the "offset so it fits in 16 bits" rationale literally true, and
    puts the packet and the log on the same p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
    [oapogee.kicad_sch]
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2026-08-12 Stop silencing the hardware install, and untrack the tscircuit build cache
    make hw-deps failed once in CI and the log said only that it had failed, because
    --silent swallowed the reason. It now runs npm ci, so the lockfile governs and a
    CI run cannot resolve a different tree than a local one, and it is not silenced.
    A clean npm ci of the same lockfile completes in four seconds locally, so the
    failure looks transient; the point of this change is that the next one will say
    why.
    Also untracks hardware/.tscircuit/ and hardware/oapogee.circuit.json. The CLI
    writes both beside the source and they went into the audit commit unnoticed:
    28 files of build cache in a repository people are meant to be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
    [oa_health.h, test_oa_packet.c]
2026-08-13 Fix the schematic viewer: React was detaching the node the zoom mutated
    Pan and zoom stopped working entirely. The symptom was precise and baffling: the
    zoom readout counted up, the pointer handlers fired, and the drawing never
    moved.
    The cause is that React owns any element it renders with
    dangerouslySetInnerHTML and re-applies that html when the component re-renders.
    The viewer mutates the SVG's viewBox directly, because that is the only way to
    zoom vectors without rasterising them, so the first state change replaced the
    SVG node and silently detached the one the effect had taken hold of. Every
    subsequent viewBox write landed on an element no longer in the document.
    The injected sheet is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
2026-08-13 Land the firmware core, and check the two implementations against each other
    firmware/ is the portable half of the payload firmware: sixteen modules and
    thirteen test binaries, C11, no allocation, no globals, buildable and testable on
    a laptop with nothing installed but cmake and a compiler. It builds clean under
    warnings-as-errors and all thirteen pass. Nothing in it has run on hardware, and
    the port layer is declarations only, because a driver that cannot be tested would
    look far more finished than it is.
    The most valuable thing here is not the firmware. It is that there are now two
    implementations of docs/spec/telemetry-packet.md in this repository, in C and in
    TypeScript, written from t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
2026-08-13 Compare the filter's outputs, not its padding
    test_oa_fusion asserted determinism with memcmp over the whole struct, which
    reads the padding between members. No assignment writes padding and the compiler
    may leave it holding whatever was on the stack, so the test passed under clang
    and failed under gcc: it claimed the filter was non-deterministic when what was
    non-deterministic was the padding. Determinism is a claim about the filter's
    outputs, so that is what it now compares.
    One other site had the same latent bug, comparing two configs parsed
    independently from LF and CRLF text, and both are now zeroed first. The three
    remaining memcmp comparisons are sound and were left alone: each follo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
2026-08-13 Make the bill of materials match the board, and link real retailers
    The parts list and the schematic had drifted apart immediately and silently. The
    circuit gained an arming switch, a battery sense divider, I2C pull-ups, USB-C CC
    pulldowns and decoupling; the bill of materials listed none of them. Twenty-six
    components on the drawing, fourteen on the page. A builder following the parts
    list could not have populated the board, and nothing said so, because the two
    files had no relationship a machine could check.
    They do now. Every part carries the reference designators it covers, and
    make data fails if a designator on the schematic is claimed by no part, if a
    part claims a designator that is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
2026-08-13 Rebuild the bill of materials around the question people arrive with
    The page put quantities in a table and buying information in a separate stack of
    twenty-six cards further down, so ordering a single part meant scrolling between
    two places and matching parts by name by eye. It also carried a price column in
    which every cell read "not priced", which is a column of noise wearing the
    costume of data, and it embedded the schematic that already has its own page.
    A reader arrives having already decided on a tier and a build path. That is now
    the only control, and everything follows from it: one row per part you actually
    need, grouped the way you shop, with the link that actually buys it. Which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
2026-08-13 Fix what the second audit found, and the checks that let it through
    Six auditors, each followed by a verifier told to refute rather than agree.
    Thirty-four findings survived. The blockers, and what each one turned out to be:
    The pod base exported as two disconnected solids. The spigot that locates the
    two halves was inset by a print clearance from the cavity wall it was supposed
    to continue, so its whole underside hung over void: a pod, and a loose
    rectangular ring, in one file. I had called this model verified on the strength
    of "manifold, genus 2", and neither of those says anything about whether the
    pieces touch. render-mechanical now counts connected surfaces and refuses to
    write a part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
    [oapogee-pod-base.stl, oapogee-pod-cap.stl, oapogee-sled.stl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]
2026-08-13 Close the rest of the audit, mostly by making the checks mean what they say
    Every fix here has the same shape: a rule the project already stated, that
    nothing enforced, and that had therefore already been broken somewhere.
    CI never ran the web test suite. Thirty-two tests guard the TypeScript half of
    the packet spec, which is the independent implementation `make crossimpl`
    compares the firmware against, and they ran only on a laptop while the Makefile
    called itself "everything CI runs". It was false in both directions: CI also ran
    check-hw, which `make check` omitted. Both now match.
    The browser encoder wrote the flags byte unmasked, so a caller could put
    reserved bit 7 on the air from the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
    [oapogee-pod-base.stl, oapogee-pod-cap.stl, oapogee-sled.stl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]
2026-08-13 Decide the open questions that were mine to decide
    Eleven questions sat marked TODO(confirm), which means an open decision rather
    than a missing measurement. Most of them had all the evidence needed to settle
    them already in the repository, and were open because nobody had sat down and
    chosen. That is not the same as being blocked.
    The sled is BT-55 and the 24 mm case is external-pod only. The geometry decided
    this rather than a preference: the circuit source puts the board at 22 mm wide,
    a BT-50 bore is 24.13 mm, and that leaves 0.6 mm of rail on each side, which a
    slicer will emit and a landing will break. BT-55 gives 4.8 mm. It costs nothing,
    because the pod already covers the small-tube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
    [oapogee-pod-base.stl, oapogee-pod-cap.stl, oapogee-sled.stl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]
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2026-08-13 Route the board
    The RP2350's pinout is no longer a placeholder, and everything downstream of it
    The 60 pins came from the Raspberry Pi datasheet, checked rather than taken on
    trust: a community pinout gave one answer, and reconstructing the package
    diagram on page 16 of RP-008373 gave the same answer pin for pin. That also
    settled something the placeholder had hidden, which is that the part's ground is
    the centre exposed pad and not a numbered pin at all. Signals are assigned to
    GPIOs their peripherals can actually mux to: I2C0 on GPIO4 and 5, SPI0 on 16, 18
    and 19, UART1 on 24 and 25, the battery sense on the one GPIO wired to the ADC.
    Two things fell out of doing it properly. The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
    [oapogee.kicad_sch]
2026-08-13 Verify the routed artifacts by source hash, not by bytes
    CI failed on `oapogee-pcb.svg does not match the source` while the same command
    passed locally. The autorouter is deterministic on one machine, checked by
    rendering three times for an identical hash, and produces a different result on
    CI's Linux than on macOS. A byte comparison of a routed board is therefore
    asking the wrong question.
    Dropping the comparison and checking nothing would be worse, because the mistake
    that actually happens is editing the circuit and forgetting to re-render. So the
    artifacts carry a hash of the source they came from, the same pattern the
    printed parts already use, and CI verifies that instead. Confirmed it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
    [oapogee.kicad_sch]
2026-08-13 Record what was tried against the autorouter's shorts
    The remaining blocker is 55 pairs of copper on the same layer, on different
    nets, closer than a fab will build, and the closest is negative, meaning they
    cross. Three attempts to make the router produce a clean board, all recorded in
    the check's own message so the next person does not repeat them:
    Raising autorouter traceClearance to 0.2 mm changed nothing. Identical trace
    count, identical via count, identical 55 violations, so the setting is either
    not reaching the router or not what it sounds like.
    The sequential_trace preset lays no copper at all: 0 traces, 40 nets unrouted.
    A four-layer board did not finish routing in ten minutes a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
    [oapogee.kicad_sch]
2026-08-14 The board is orderable
    Fabrication blockers: none. `make fab` opened, and the repository now carries a
    complete package: both copper layers, mask, paste and silkscreen on both sides,
    edge cuts, plated and non-plated drill files, the bill of materials and the pick
    and place. 27 components, 95 routed traces, 154 vias.
    Two things got it there, and one of them was me being wrong.
    The traces are 0.127 mm now. Clearance is centre distance minus half of each
    width, so narrowing the copper buys clearance directly, and the router's own
    internal margin turned out to be the binding constraint at about 0.115 mm no
    matter what it was given. That was worth establishing rather than guessing at:
    every loc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
    [oapogee.kicad_pcb, oapogee.kicad_sch]
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2026-08-15 The board could be flashed once and then never again
    A page verification pass across the whole site found a hardware defect, which is
    not where I expected one to come from.
    RUN, SWCLK and SWDIO were all NOT_CONNECTED in the generated netlist, and
    QSPI_CS went only to the flash. There is no dedicated bootloader pin on this
    microcontroller: holding the flash chip select low as the chip leaves reset is
    what selects USB boot. So a fabricated board could have been programmed exactly
    once, while its flash was still blank and the bootrom fell through to USB, and
    after that there would have been no way into the bootloader, no way to reset it,
    and no way to attach a debugger. For a payload meant to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
    [oapogee.kicad_pcb, oapogee.kicad_sch]
2026-08-15 Make both encoders obey the rule they both claimed to
    The two implementations of the packet format disagreed about a wire invariant,
    and the cross-implementation check passed anyway because no vector exercised it.
    The format says with no fix there is no last value worth carrying, so lat_e7 and
    lon_e7 carry INT32_MIN in both BEACON and POSITION and GNSS_FIX says which it
    is. The browser encoder enforced that for POSITION and not for BEACON, so one
    encoder held two rules. The firmware enforced neither: bodies are written by an
    X-macro that copies fields verbatim, so a caller could put a real coordinate
    behind a clear flag and it went on the wire.
    Deciding which side to change took some care.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
    [oa_packet.c, oa_packet.h, oa_vectors.c]
2026-08-15 Choose the regulator, and find out the board had outgrown itself
    U2 was manufacturerPartNumber="TODO-BUCK-BOOST" on a five pin SOT-23, which is a
    placeholder standing in for the part that feeds everything else. It is a
    TPS63001 now, and every figure behind that choice comes from TI's datasheet
    SLVS520C rather than from memory: 1.8 V to 5.5 V in, which spans a single
    lithium cell from full charge to cutoff; fixed 3.3 V out, so there is no
    feedback divider and no resistor pair to get wrong; up to 800 mA; 40 uA typical
    quiescent at no load; VSON-10, 3 by 3 mm, exposed pad to PGND; one external
    2.2 uH inductor, which is now L2.
    Quiescent current decided it rather than efficiency at load. This p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
    [oapogee-pod-base.stl, oapogee-pod-cap.stl, oapogee-sled.stl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]
2026-08-15 Replace the addressable LED, and catch the export lying about it
    The status LED is three plain dice in one package now, driven by three pins
    through three resistors, rather than an addressable part on one. The reason is
    in the bill of materials: the WS2812 family wants a supply above the only rail
    this board has, and a part run under its minimum works for whoever tested it and
    does something else cold. One resistor per colour because the three dice do not
    share a forward voltage, so a single shared one gives three brightnesses and no
    way to fix one without moving the others.
    Doing it exposed something worse than the LED.
    Renaming three pins on the microcontroller left a stale entry in its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
    [oapogee.kicad_pcb, oapogee.kicad_sch]
2026-08-16 Choose the remaining parts, and fix what the datasheets said was wrong
    The bill of materials had eleven rows with no part behind them, which meant
    the design was not actually finished: several of those rows decide how the
    board behaves rather than just what it costs. Reading the datasheets to close
    them turned up two things the schematic had wrong.
    The buck-boost's output capacitor was 10 uF. SLVS520C section 8.2.2.3.2 asks
    for a nominal 15 uF, and a small ceramic delivers well under its marked value
    under DC bias, so the rail was short of the datasheet twice over. C1 and C2
    were one BOM line and are now two, because the datasheet asks for two values:
    at least 4.7 uF in, 15 uF nominal out.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
    [oapogee.kicad_sch]
2026-08-16 Add the crystal, without which the board cannot be flashed
    XIN and XOUT were declared on the RP2350 and connected to nothing. That is not
    a missing refinement, it is a dead board: "Hardware design with RP2350" chapter
    4 says the internal oscillator's frequency is not well defined or controlled,
    varying by chip, supply and temperature, and that applications relying on exact
    frequencies are not possible without an external source, naming USB as the
    example. USB is the only connector this board has and drag-and-drop UF2 loading
    is why this microcontroller family was chosen at all.
    Every value is Raspberry Pi's. Y1 is the ABM8-272-T3 they specify and the Pico 2
    uses. C4 and C5 are 15 pF, which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
    [oapogee.kicad_sch]
2026-08-16 Measure the printed parts instead of not saying how big they are
    The Mounting page could not answer the first question anybody printing a part
    asks, which is whether it fits on their bed and in their rocket. The number was
    not in data/mechanical.yaml, and it could not honestly be typed in: the parts
    are built from 28 parameters through unions, differences and a hull, so the
    envelope is an output of the geometry rather than an input to it, and a
    hand-entered figure would drift the first time a wall thickness moved.
    So it is measured off the exported triangles on every `make mech` and rendered
    beside each part. Pod base 136.8 x 31.8 x 15.9 mm, pod cap 127.9 x 31.8 x
    8.7 mm, sled 127.4 x 32.3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
    [oapogee-pod-cap.stl]
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2026-08-16 The GNSS receiver had no antenna, and a footprint that did not exist
    RF_IN was declared on the receiver and connected to nothing. That is a Track
    tier that cannot produce a position, which is the one thing that tier exists
    for, and it is the second defect of exactly this shape after the crystal: built
    cleanly, routed cleanly, exported a clean Gerber package, passed every check
    here. A pin nobody connects looks identical to a pin nobody needed.
    Fixing it turned up a third. J5 was given `footprint="ufl"`, which tscircuit
    does not have. That is not an error that stops anything: the export logs an
    invalid-property message, exits zero, and builds the component with no pads at
    all. A part with no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
    [oapogee.kicad_sch]
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2026-08-16 Build the radio properly: the real SX1262 pinout, its crystal, its DC-DC
    Semtech DS.SX1261-2.W.APP Table 2-1, transcribed for the QFN 4x4 24L and
    cross-checked against revision 1.2 from 2019 and revision 2.2 from 2024. The
    part had nine of twenty-five pins named. It has all of them now, and the four
    supplies, four grounds, exposed pad, reset and DIO2 are wired.
    Two parts the datasheet requires that this board did not have:
    Y2, a 32 MHz crystal, because the radio has no reference without one. And it
    gets no load capacitors, which looks like an omission next to the
    microcontroller's crystal ten millimetres away and is not. Section 4.1.3: the
    SX1262 "does not require the user to set external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
    [oapogee-pod-base.stl, oapogee-pod-cap.stl, oapogee-sled.stl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]
2026-08-16 The allowlist said these numbers could not drift, and they drifted
    check-prose exempts a figure when somebody records why it is safe. One entry
    covered the board width, the board length and the rail arithmetic derived from
    them, on the reasoning that a dimension "declared in data/mechanical.yaml and
    cross-checked against the circuit source by check-data ... cannot drift."
    check-data compares those two against each other. It has no idea what the prose
    says. So when the board grew, four pages went on quoting the old width and the
    arithmetic built on it, and the allowlist is precisely what let them through:
    reference.md "The board is 22 by 60 mm"
    faq.md a 22 mm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
    [oapogee-pod-base.stl, oapogee-pod-cap.stl, params.scad]
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2026-08-17 Transcribe all seven remaining pinouts, and two of them were fatal
    Six datasheets read by parallel agents, each verified by a second agent working
    from an independently obtained source, usually a different revision or a
    different mirror. Every disagreement they found was provenance or figure
    numbering. Not one pin assignment was disputed. The seventh, the LED, is handled
    below.
    Two of the seven guesses this replaces would have produced a dead board:
    The barometer had SDA on pin 3, and pin 3 of a BMP390 is VSS. That is the I2C
    data line shorted to ground, which takes out the bus rather than just the part.
    The IMU had VDD on pin 1, and pin 1 of an ICM-42688-P is AP_SDO, the part's own
    data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
    [oapogee-pod-base.stl, oapogee-pod-cap.stl, oapogee.kicad_sch]
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

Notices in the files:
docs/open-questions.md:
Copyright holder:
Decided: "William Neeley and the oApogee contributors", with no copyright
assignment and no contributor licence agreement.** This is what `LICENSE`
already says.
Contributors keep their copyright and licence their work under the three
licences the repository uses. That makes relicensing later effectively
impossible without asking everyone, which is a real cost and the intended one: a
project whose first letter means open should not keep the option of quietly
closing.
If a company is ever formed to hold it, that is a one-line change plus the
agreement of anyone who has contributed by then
